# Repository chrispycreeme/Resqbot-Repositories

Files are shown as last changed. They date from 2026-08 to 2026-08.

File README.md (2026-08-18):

# ResQBot: Dual-Node Multi-Sensor Reconnaissance & Search Platform

## Overview

ResQBot is an integrated search and rescue reconnaissance platform designed for real-time human detection, thermal mapping, and remote navigation in hazardous or restricted environments. The system utilizes a dual-microcontroller architecture (ESP32-CAM and ESP32-Main) communicating over a local Wi-Fi network with a central Python desktop station. 

Key capabilities include:
* Real-time visual reconnaissance via ESP32-CAM streaming JPEG frames over HTTP POST.
* Computer vision human detection utilizing YOLO object detection (`person.pt`).
* Infrared thermal telemetry using an MLX90640 array sensor (768-pixel temperature grid) rendered as JET heatmaps.
* Differential propulsion drive utilizing L9110 motor drivers with software-controlled PWM ramping.
* Onboard status monitoring via SSD1306 OLED display and active acoustic buzzer alarms.
* Provisioning interface via captive Wi-Fi Access Point portals on both microcontrollers.
* An interactive web-based technical manual and troubleshooting suite.

---

## Repository Structure

```
resqbot-final/
├── 3D Parts/
│   ├── Compartment.stl          # 3D printable electronics compartment chassis
│   ├── Hinge.stl                # 3D printable door hinge assembly
│   ├── Latch.stl                # 3D printable mechanical enclosure latch
│   ├── Left Hull.stl            # 3D printable left hull section
│   ├── Right Hull.stl           # 3D printable right hull section
│   ├── 1.png                    # Assembly preview / render 1
│   ├── 2.png                    # Assembly preview / render 2
│   ├── 3.png                    # Assembly preview / render 3
│   └── 4.png                    # Assembly preview / render 4
├── esp32cam/
│   └── esp32cam.ino             # ESP32-CAM firmware (OV2640 camera capture, HTTP video uploader)
├── esp32main/
│   └── esp32main.ino            # ESP32-Main station firmware (MLX90640, SSD1306 OLED, L9110, Buzzer)
├── manual_web/
│   ├── index.html               # Web-based operations and technical manual interface
│   ├── styles.css               # Manual stylesheet
│   ├── script.js                # Interactive hotspots, zoom controls, and simulation logic
│   └── perfboard_view.png       # Annotated circuit wiring diagram image
├── python/
│   ├── app.py                   # Central Python desktop app (Flask HTTP server + Tkinter GUI)
│   └── person.pt                # Trained YOLO neural network weights for human detection
├── Project_Price_Quotation_ResqBot_Final.pdf  # Bill of materials and cost breakdown documentation
├── Resqbot Model Specifications.pdf  # Model specifications / CAD documentation
├── ResqBot Schematics.pdf        # Schematic electrical wiring diagrams
└── README.md                    # System documentation
```

---

## Hardware Subsystems

### 1. ESP32-CAM Node
* **Processor:** ESP32 Dual-Core 240 MHz MCU.
* **Sensor:** OV2640 Camera Module (VGA / QVGA resolutions).
* **Role:** Continuous capture of JPEG image frames transmitted via HTTP POST requests to `/upload_cam` on the central server.
* **Provisioning:** Hosts captive access point `ResQBot-CAM-AP` at `192.168.4.1` for configuring Wi-Fi credentials and target host server IP into non-volatile storage (NVS).

### 2. ESP32-Main Control Unit
* **Processor:** ESP32 Dual-Core 240 MHz MCU.
* **Thermal Sensor:** GY-MCU90640 (MLX90640 32x24 IR array) over UART (115200 baud, 1544-byte frame buffer).
* **Display:** 0.96-inch SSD1306 OLED (128x64 pixels, I2C bus at `0x3C`/`0x3D`).
* **Motor Driver:** L9110 Dual Channel H-Bridge Motor Driver supporting PWM speed ramping for Motor A and Motor B.
* **Alarm:** Active 5V Piezo Buzzer triggered on detection alerts or server requests.
* **Provisioning:** Hosts captive access point `ResQBot-Main-AP` at `192.168.4.1` for Wi-Fi and host IP configuration into NVS.

### 3. Power and Electrical Regulation
* **Primary Source:** 3S Li-ion Battery pack.
* **Voltage Regulation:** LM2596 DC-DC Buck Converter calibrated to 5.00V DC.
* **Charging Interface:** Integrated 3S Type-C charging circuit with status LED indication.
* **Switching Isolation:** Dual-position Rocker Switch toggling between System Power ON (Position I) and Charge Mode (Position O) to protect onboard microcontrollers during charging.

### 4. Structural Hull and Mechanical CAD
* STL files for full hull assembly are provided in the `3D Parts/` folder, including Left and Right Hulls, Electronics Compartment, Hinge, and Latch mechanisms.

---

## Technical Specifications

### 1. Computer Vision AI Model Specifications
* **Model Architecture:** YOLO (You Only Look Once) neural network object detector optimized for real-time human detection.
* **Weights File:** `person.pt`
* **Target Class:** Class `0` (Person / Human Detection).
* **Confidence Threshold:** `0.35` (`conf=0.35`).
* **Input Resolution:** Scaled to 480x360 pixels from incoming JPEG video streams (VGA / QVGA).
* **Inference Pipeline:** PyTorch / Ultralytics YOLO inference integrated with OpenCV bounding box annotations and automatic buzzer alert triggers.

### 2. Microcontroller & Processing Specifications
* **ESP32-Main Node:**
  * Processor: Tensilica Xtensa Dual-Core 32-bit LX6 @ 240 MHz.
  * Memory: 520 KB SRAM, 4 MB Flash memory.
  * Wireless Connectivity: Wi-Fi 802.11 b/g/n, Bluetooth v4.2 BR/EDR & BLE.
  * Operating Voltage: 3.3V Logic (5.0V VCC input from buck regulator).
* **ESP32-CAM Node:**
  * Module Type: AI-Thinker ESP32-CAM.
  * Camera Sensor: Omnivision OV2640 2 MP Image Sensor.
  * Video Formats: JPEG streaming over HTTP POST at VGA (640x480) / QVGA (320x240).
  * External Memory: 4 MB PSRAM for multi-buffer frame buffering.

### 3. Sensor Module Specifications
* **Far-Infrared Thermal Sensor (GY-MCU90640 / MLX90640):**
  * Sensor Array Resolution: 32 x 24 IR pixels (768 total temperature data points).
  * Field of View (FOV): 55° x 35° / 110° x 75°.
  * Temperature Measurement Range: -40°C to +300°C.
  * Interface: Hardware UART @ 115200 Baud (1544-byte raw frame packet).
* **Ultrasonic Distance Sensor:**
  * Interface: Serial UART (GPIO 5 TX / GPIO 18 RX).
* **Status OLED Display:**
  * Screen Size: 0.96 inch SSD1306 Monochrome Display.
  * Resolution: 128 x 64 pixels.
  * Bus Protocol: I2C (Default address `0x3C` / `0x3D`, SDA GPIO 21, SCL GPIO 22).
* **Acoustic Alert:**
  * Active 5V Piezoelectric Buzzer on GPIO 27.

### 4. Propulsion & Motor Control Specifications
* **Motor Driver:** L9110S Dual-Channel H-Bridge Motor Driver Module.
* **Continuous Current:** 800 mA per channel (1.5 A peak).
* **Operating Voltage:** 2.5V to 12V DC.
* **Control Method:** 4-Channel PWM speed ramping (5 kHz frequency, 8-bit resolution: 0 - 255).
* **Drive System:** Differential steering (Independent Left/Right propulsion thrusters).

### 5. Power & Voltage Regulation Specifications
* **Battery Pack:** 3S Li-ion Battery Configuration (11.1V nominal, 12.6V max charge).
* **Logic Voltage Regulator:** Mini-360 / LM2596 DC-DC Buck Converter outputting 5.00V DC for MCU and sensor logic.
* **Motor Voltage Regulator:** Dedicated Mini-360 DC-DC Buck Converter supplying high-current power rail for L9110 motor driver.
* **Charging Interface:** Integrated 3S 2A Type-C Lithium Battery Charger Module with series cell balancing (`B+`, `B2`, `B1`, `B-`).

---

## Software Architecture

### Central Desktop Control Station (`python/app.py`)
The primary operator interface combines a multi-threaded Flask HTTP server with a Tkinter dashboard interface:

1. **Flask API Endpoints:**
   * `POST /upload_cam`: Ingests binary JPEG camera frames from the ESP32-CAM.
   * `POST /upload_mlx`: Ingests 768-element floating-point temperature arrays from the ESP32-Main. Returns motor target speeds and active person detection counts.
   * `GET/POST /motor`: Provides query and command interfaces for differential motor channels.
   * `GET/POST /motorStop`: Issues immediate emergency stop commands to both motor channels.

2. **Computer Vision & Thermal Pipeline:**
   * **YOLO Person Detection:** Processes incoming visual frames against `person.pt` model weights, drawing bounding boxes and calculating total detected individuals.
   * **Thermal Heatmap Processing:** Normalizes raw temperature matrices and applies the OpenCV `COLORMAP_JET` transformation, displaying localized minimum, maximum, and average temperatures.

3. **WASD Steering & Speed Ramping Engine:**
   * Maps keyboard inputs (`W`, `A`, `S`, `D`, `Spacebar`) into differential motor targets for Forward, Reverse, Spin Left, Spin Right, and Emergency Stop operations.
   * Implements software ramping algorithms to ensure smooth acceleration and deceleration curves.

---

## Web Operations Manual (`manual_web/`)

The repository includes a web-based technical manual that can be rendered in any modern web browser. Features include:
* **System Architecture Breakdown:** Technical descriptions of hardware and software workflows.
* **Interactive Hardware Viewer:** Circuit diagram navigation with zoom, pan, and interactive hotspots describing pin connections.
* **Commissioning Timeline:** Step-by-step startup, calibration, provisioning, and charging procedures.
* **Filterable Troubleshooting Matrix:** Searchable resolution protocols for power, camera, thermal sensor, motor driver, display, and network issues.
* **Control Simulator:** Integrated keyboard steering and motor PWM output preview tool.

---

## Getting Started

### System Prerequisites
* **Python Environment:** Python 3.10 or higher.
* **Firmware Build Environment:** Arduino IDE with ESP32 board support packages (`esp32` by Espressif Systems).

### Python Dependencies Installation
Install required dependencies prior to launching the control station:
```bash
pip install ultralytics opencv-python pillow flask requests numpy
```

### Firmware Flashing
1. **ESP32-CAM Node:**
   * Open `esp32cam/esp32cam.ino` in Arduino IDE.
   * Select board: **AI Thinker ESP32-CAM**.
   * Enable PSRAM if supported by your module.
   * Flash firmware to the ESP32-CAM board.

2. **ESP32-Main Station:**
   * Open `esp32main/esp32main.ino` in Arduino IDE.
   * Select board: **ESP32 Dev Module**.
   * Required libraries: `Adafruit_GFX`, `Adafruit_SSD1306`, `Preferences`, `Wire`, `WiFi`, `HTTPClient`.
   * Flash firmware to the ESP32-Main board.

### Commissioning and Operation Workflow

1. **Power Supply Calibration:**
   * Set the Rocker Switch to Position O (Charge Mode).
   * Disconnect microcontrollers from the 5V rail.
   * Toggle Rocker Switch to Position I and verify LM2596 output reads exactly 5.00V DC using a multimeter.

2. **Launch Control Station Server:**
   * Navigate to the `python/` directory and run:
     ```bash
     python app.py
     ```
   * Record the host IP address displayed in the window title bar (e.g., `http://192.168.18.155:5000`).

3. **Network Provisioning:**
   * **ESP32-CAM:** Connect PC or mobile device to Wi-Fi AP `ResQBot-CAM-AP`. Open browser at `http://192.168.4.1`, input your Wi-Fi SSID, Password, and Server Host IP, then click **Connect & Continue Operations**.
   * **ESP32-Main:** Connect to Wi-Fi AP `ResQBot-Main-AP`. Open browser at `http://192.168.4.1`, input identical Wi-Fi SSID, Password, and Server Host IP, then click **Connect & Continue Operations**.

4. **Telemetry Verification and Control:**
   * Observe OLED status on the main node: verify Wi-Fi connection, Python app connection status, and MLX sensor readiness.
   * Monitor the desktop station GUI for video feeds, person bounding boxes, and thermal heatmaps.
   * Drive the robot using WASD keys or on-screen slider controls.

---

## Telemetry and API Endpoint Reference

| Endpoint | Method | Payload / Parameters | Description |
| :--- | :--- | :--- | :--- |
| `/upload_cam` | `POST` | Binary JPEG buffer | Receives image frame from ESP32-CAM node |
| `/upload_mlx` | `POST` | JSON array of 768 float values | Receives thermal telemetry array from ESP32-Main node |
| `/motor` | `GET / POST` | `ch` (A/B), `speed` (-255 to 255) | Queries or updates target channel speeds |
| `/motorStop` | `GET / POST` | None | Halts both motor channels immediately |
| `/beep` | `GET / POST` | `ms` (duration in milliseconds) | Triggers active buzzer alert |

---

## Safety Guidelines

* **Charging Isolation:** Always toggle the main Rocker Switch to Position O (Charge Mode) before connecting a Type-C charging cable. Charging while the system is powered on can damage sensitive electronics.
* **Reverse Polarity Warning:** Verify wiring connections against `ResqBot Schematics.pdf` before applying battery power. Reversed polarity will destroy microcontroller components.
* **Thermal Management:** Ensure LM2596 regulator and L9110 motor driver modules have sufficient airflow during high-load motor operations.

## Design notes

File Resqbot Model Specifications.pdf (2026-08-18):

# TECHNICAL SPECIFICATIONS

# ResqBot - Catamaran Based Chassis

# 1. Executive Summary & Design Overview

The structural, dimensional, and material specifications for a lightweight, twin-hull (catamaran). Specifically for additive manufacturing using PETG (Polyethylene Terephthalate Glycol).

The catamaran-style configuration provides enhanced lateral stability in surface water conditions, while space-frame lattice arms distribute dynamic loading from the pontoon hulls into the central payload compartment.

# 2. Bounding Dimensions & Physical Envelope

Dimension Parameter | Value | Description / Reference
Overall Length (OAL) | 409.00 mm | Maximum longitudinal profile along the pontoon axis
Overall Beam (Width) | 412.00 mm | Total horizontal span from port to starboard hull outer edges
Overall Height (OAH) | 180.00 mm | Total vertical height from keel base to tail fin apex
Lattice Arm Diagonal Span | 199.25 mm | Structural truss frame length connecting hulls to central bay
Pontoon Mount Footprint | 110.90 × 52.00 mm | Contact interface block for lattice arm pontoon mounting
Central Bay Footprint | 171.05 × 130.49 mm | Top deck profile envelope for main payload compartment

# 3. Material & Structural Wall Thickness Profile

To optimize displacement and weight distribution while maintaining mechanical strength under wave impact, the chassis utilizes a differential wall thickness strategy:

+-----------------------------------------------------------------------+
| SUB-ASSEMBLY ZONE | | PETG WALL THICKNESS | SLICER / PRINT SPEC | |
+------------------------+---------------------+------------------------+
| Hinge Joints & Fins | | 4.0 mm - 5.0 mm | | 10+ Perimeters / Solid |
| Central Bay & Arms | | 2.5 mm - 3.0 mm | | 6-7 Perimeters | |
| Pontoon Hulls | | 2.0 mm - 2.5 mm | | 5-6 Perimeters | |
+-----------------------------------------------------------------------+

## 3.1 Fabrication & Slicer Specifications

- Primary Filament: PETG (Polyethylene Terephthalate Glycol)
- Pontoon Shells ( | ): Designed to minimize dead weight below
the waterline while providing sufficient impact resistance against debris.
- Central Bay & Lattice Arms ( | ): Higher wall density to
absorb hull torsion during differential wave action and support internal payload mass.
- Hinge Assemblies & Tail Fins ( | ): Near-solid printing
required around pivot pin bores to handle shearing stress and dynamic tail fin drag.

# 4. Subsystem Layout & Internal Architecture

## 4.1 Pontoon Hulls (Port & Starboard)

- Hull Geometry: Hydrodynamic, low-drag displacement profile with a tapered bow.
- Internal Cavity: Hollow pontoon structure yielding an estimated
internal volume of | per hull.
- Reserve Buoyancy Integration: High-density, custom-trimmed EVA foam blocks are inserted directly into the hollow pontoon cavities to guarantee positive flotation in the event of an outer shell breach.
- Retention Method: Secured via friction fitting or marine-grade silicone adhesive (RTV sealant). No internal structural recessed channels are needed.

## 4.2 Structural Lattice Arms

- Truss Architecture: Triangular space-frame geometry designed to distribute hydrodynamic drag evenly across the vessel frame.
- Structural Span: | per side, providing a wide $412\text{
mm}$ total beam for stability against capsizing.

## 4.3 Central Electronics Compartment

- Envelope: | .
- Internal Component Integration: All power distribution, logic boards, battery cells, sensors, and charging modules are fully enclosed within the compartment.
- Ingress Protection Strategy: The exterior of the central housing is printed solid on all sides (no front camera/sensor aperture cutouts) to protect against head-on wave splashes. Charging terminals and debug ports remain internal; access is conducted via the top hatch.

# 5. Port Geometry & Wiring Pass-Throughs

Port Designation | Location | Dimensions | Quantity | Primary Function
Motor Ports | Rear Face | | 2 Wire lead routing | & propulsion motor mounts
Front Optics Port | Front Face | | 2 “Eye” sockets for | the camera (Thermal and Visual)
Front Middle Optic Port | Front Face | | 1 Slot for the | ultrasonic sensor right below the front optics to ensure close relative field of view.

## Sealing Protocol

To maintain watertight integrity, the rear | motor ports must
be sealed after wire harness installation using rubber cable grommets or silicone seal potting compound.

# 6. System Summary Matrix

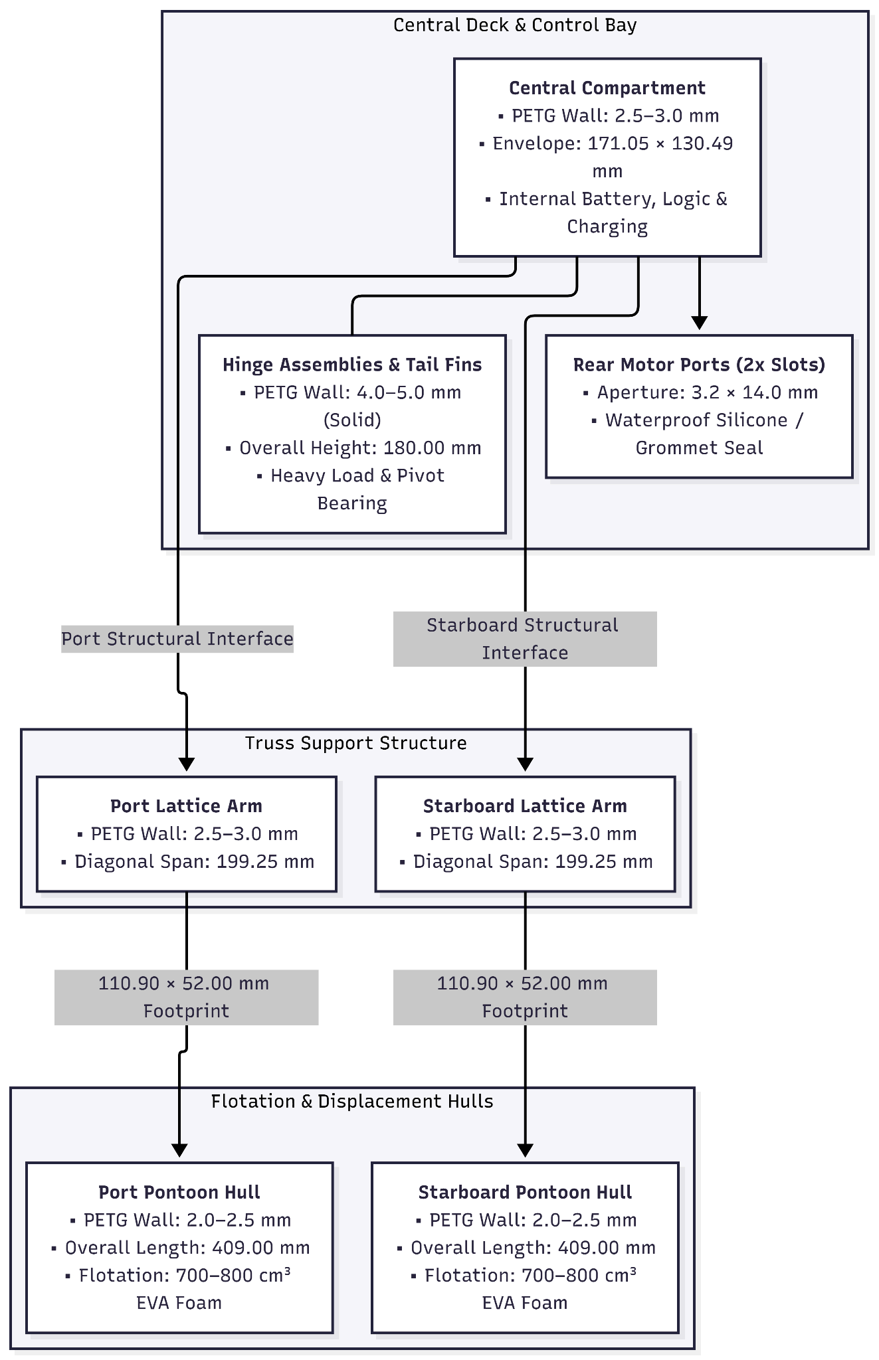
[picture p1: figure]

# 7. Complete Visual Presentation of Each Part

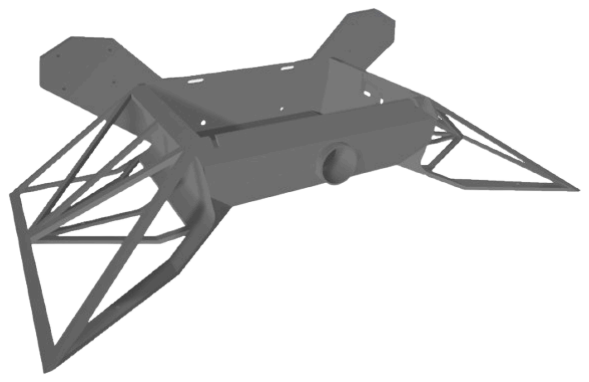
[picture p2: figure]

### A. Compartment

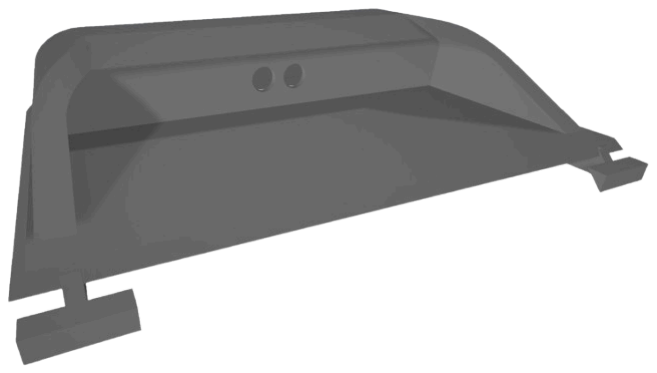
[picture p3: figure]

### B. Top Hatch / Lid

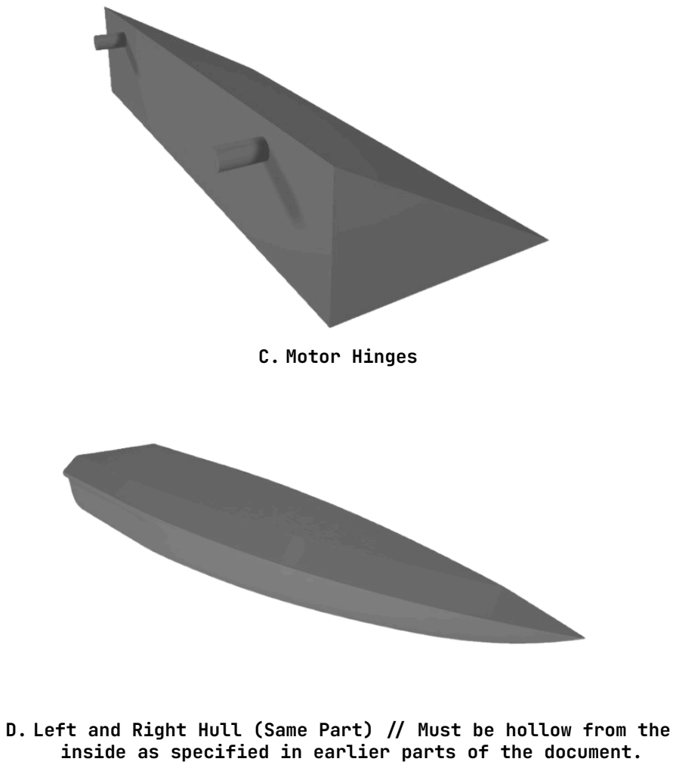
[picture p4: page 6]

### C. Motor Hinges

### D. Left and Right Hull (Same Part) / Must be hollow from the

inside as specified in earlier parts of the document.

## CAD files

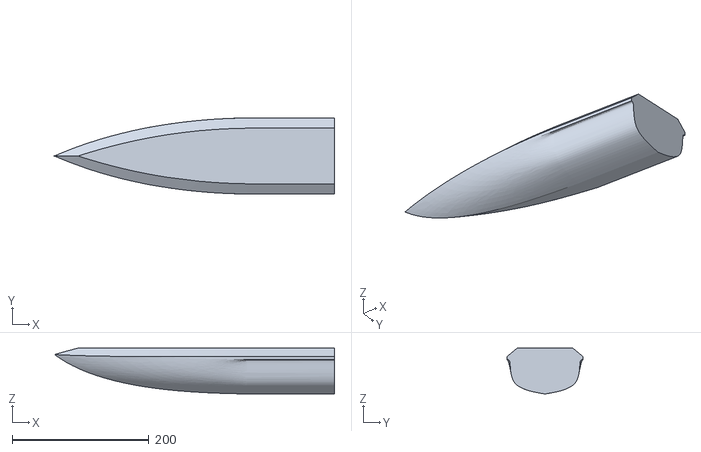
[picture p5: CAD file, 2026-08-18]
3D Parts/Right Hull.stl
409.1 x 111.2 x 67.1

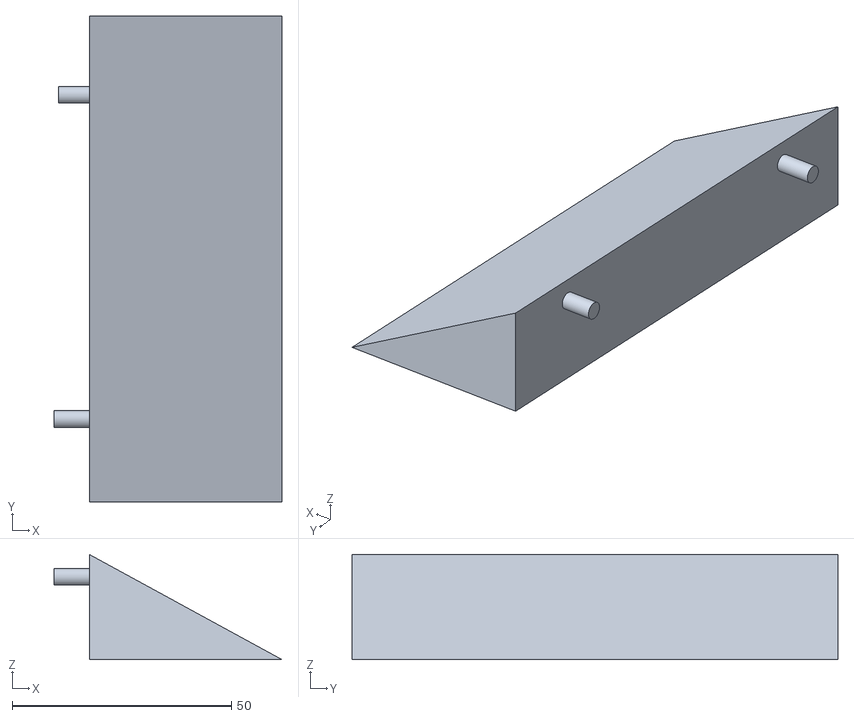
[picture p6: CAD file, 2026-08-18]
3D Parts/Hinge.stl
52.0 x 110.9 x 24.0

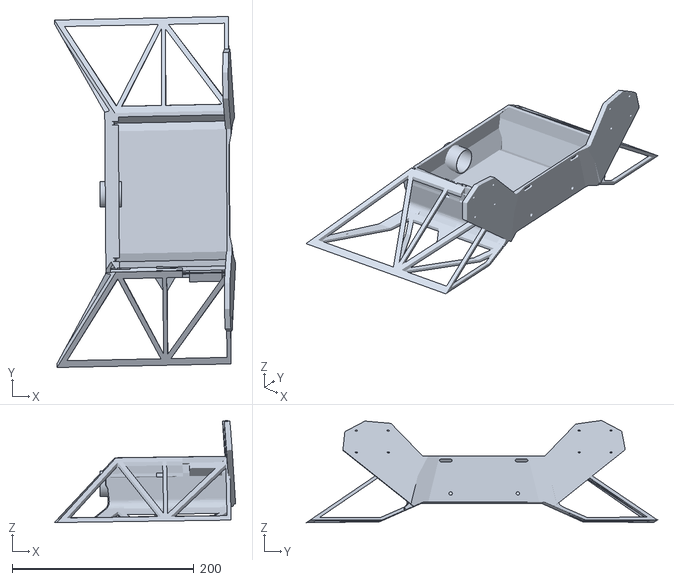
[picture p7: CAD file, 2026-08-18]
3D Parts/Compartment.stl
199.3 x 385.8 x 112.2

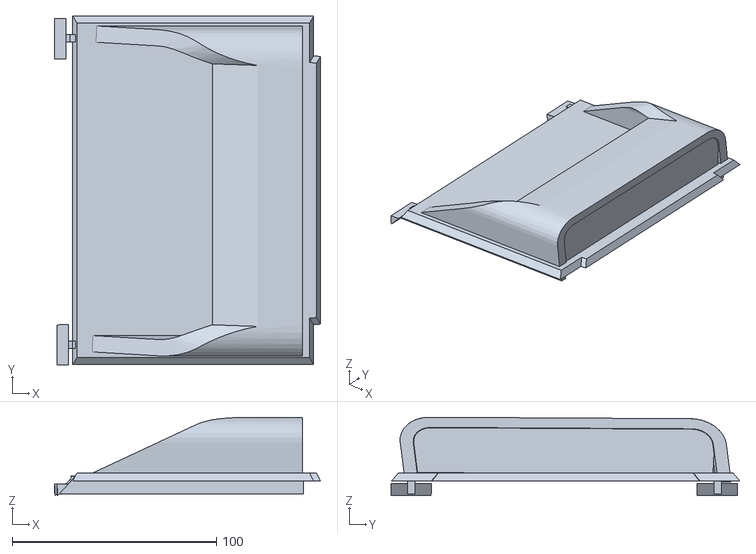
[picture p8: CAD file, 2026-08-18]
3D Parts/Latch.stl
130.5 x 171.0 x 38.5

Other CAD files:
3D Parts/Left Hull.stl

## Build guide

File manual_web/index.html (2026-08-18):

R

# ResQBot Operations & Technical Manual

REV v2.4 PLATFORM: ESP32 / PYTHON

1.0

## System Architecture & Overview

Technical breakdown of the ResQBot dual-microcontroller reconnaissance platform and desktop station integration.

### Dual Microcontroller Architecture

ResQBot utilizes two independent ESP32 microcontrollers to segregate video capture and sensor telemetry workloads:

- ESP32-CAM Node: Dedicated OV2640 camera streaming node posting binary JPEG frames over HTTP POST to the central server.
- ESP32-Main Station Node: Core processing node parsing MLX90640 thermal UART telemetry, driving the SSD1306 OLED, executing L9110 motor PWM ramping, and controlling the alarm buzzer.

### Python Control Station & AI Pipeline

The central Flask and Tkinter application hosted on the PC processes raw stream feeds in real time:

- YOLO Person Detection: Evaluates incoming JPEG frames using the person.pt neural network model.
- Thermal JET Interpolation: Converts 768 floating-point temperature values into a 24x32 color-mapped thermal matrix.
- WASD Steering Engine: Translates operator key controls into differential motor PWM speed targets.

SAFETY PROTOCOL SUMMARY

Always ensure the main Rocker Switch is set to Position O (Charge Mode) before plugging in USB Type-C charging power. Operating or charging with reversed polarity will result in permanent hardware damage.

2.0

## Perfboard Circuit Diagram

Select any numbered component pin on the diagram below to inspect technical specifications, electrical connections, operating protocols, and precautions.

Hardware Component Viewer

Zoom In (+) Zoom Out (-) Reset View Hotspots: ON

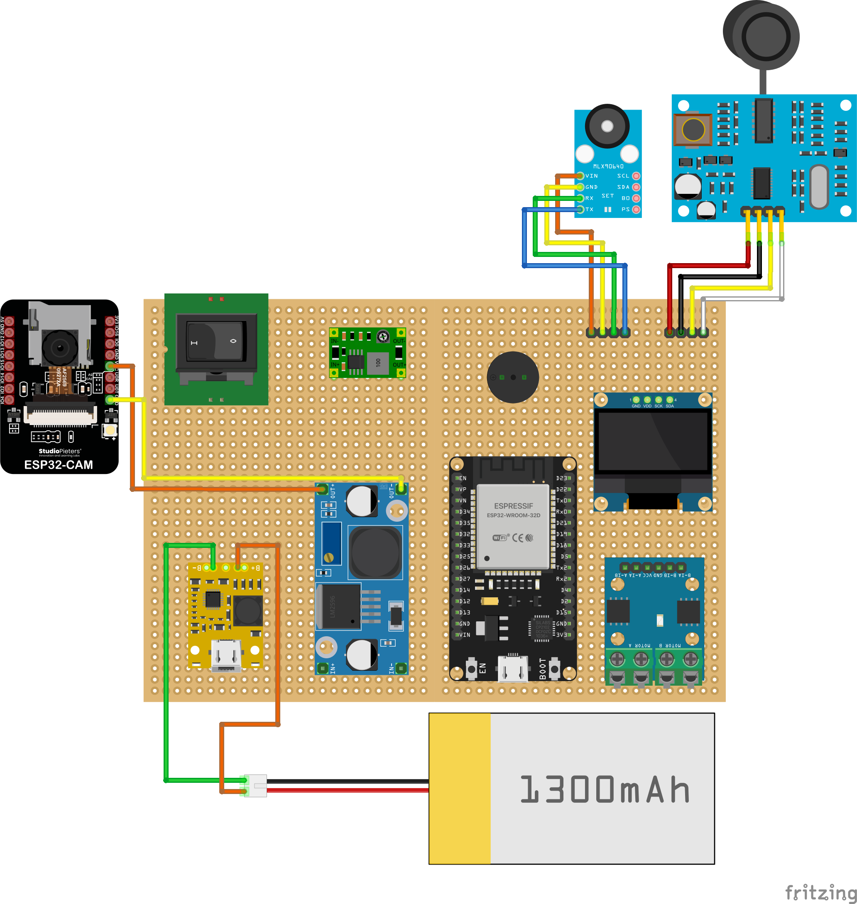
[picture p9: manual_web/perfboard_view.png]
ResQBot Perfboard Circuit Diagram


3.0

## Step-by-Step Commissioning & Boot Guide

Sequential operations workflow to safely verify hardware wiring, initialize host software, provision microcontrollers, and operate the robot.

01

Physical Wiring & Electrical Calibration

Before applying main battery power, verify all electrical connections and rail voltages using a digital multimeter.

- Confirm 3S battery leads are wired to the 3S charger module: BAT+ (Red) and BAT- (Black).
- Verify the LM2596 buck converter input terminals connect to the switched output of the Rocker Switch.
- Voltage Calibration: Disconnect microcontrollers from the 5V rail. Toggle Rocker Switch to Position I and measure LM2596 output with a multimeter. Adjust brass potentiometer until output reads exactly 5.00V DC.
- Ensure a shared common ground bus links all GND pins across ESP32-Main, ESP32-CAM, OLED, MLX sensor, Ultrasonic sensor, Buzzer, and L9110 motor driver.

02

Python Environment Setup & Model Deployment

Install required Python 3.10+ dependencies and verify neural network weight files.

Run package installation in terminal:

pip install ultralytics opencv-python pillow flask requests numpy

Confirm that the YOLO neural network model file person.pt is located inside the python/ folder.

03

Host Server Launch & Local IP Identification

Execute the central desktop control station and record the host IP address.

Start the application server:

python python/app.py

Observe the window header displaying the host address: Server Running @ http://<HOST_IP>:5000 (e.g. http://192.168.18.155:5000). Note this IP address for provisioning steps.

04

System Power On & Microcontroller AP Provisioning

Provision WiFi credentials and server target IP into NVS flash memory on both microcontrollers.

1. Toggle main Rocker Switch to Position I (System Power ON).
2. ESP32-CAM Provisioning: Connect PC/mobile to WiFi AP ResQBot-CAM-AP. Navigate browser to http://192.168.4.1. Input local WiFi SSID, Password, and Server IP. Click Connect & Continue Operations.
3. ESP32-Main Provisioning: Connect PC/mobile to WiFi AP ResQBot-Main-AP. Navigate browser to http://192.168.4.1. Input identical local WiFi SSID, Password, and Server IP. Click Connect & Continue Operations.

05

Telemetry Verification & Steering Operations

Verify active stream feeds and test differential motor steering controls.

- Inspect SSD1306 OLED display on robot: verify WiFi: Connected, Python App: Connected, and MLX: OK.
- Inspect Python Desktop App GUI: verify live camera feed with YOLO bounding boxes and thermal JET heat map display.
- Click inside Tkinter window and test WASD steering: W (Forward), S (Reverse), A (Spin Left), D (Spin Right), Spacebar (Emergency Stop).

06

Shutdown & 3S Type-C Charging Protocol

Safely isolate electronics and execute battery charging procedure.

1. Press Spacebar in app window to stop motor outputs.
2. Toggle Rocker Switch to Position O (Charge Mode) to disconnect system electronics.
3. Plug USB Type-C charging cable into 3S charger module port.
4. Verify Red LED is lit during charging. Disconnect charger once Blue LED indicates full charge.

4.0

## Subsystem Specifications & Access Point Interface

Detailed hardware and software protocols for camera streaming, thermal sensor parsing, and control desktop station.

### ESP32-CAM Node Specifications

OV2640 camera node streaming binary JPEG buffers over HTTP POST.

HTTP Telemetry Endpoint

http://<HOST_IP>:5000/upload_cam

Frame Resolution

VGA (640x480) with PSRAM enabled; QVGA (320x240) fallback.

### ESP32-Main Station Specifications

Master MCU parsing MLX90640 UART telemetry and handling motor PWM ramping.

Thermal Telemetry Endpoint

http://<HOST_IP>:5000/upload_mlx

UART Configuration

115200 Baud | 1544 Byte Frame Buffer

http://192.168.4.1/

## ResQBot Camera Module

WiFi & Host Server Setup

WiFi Network (SSID):

ResQBot_Rescue_Net

WiFi Password:

• • • • • • • •

Host PC / Server IP Address:

192.168.18.155

Connect & Continue Operations

AP IP: 192.168.4.1

Figure 4.1: ESP32-CAM Captive Portal Interface (http://192.168.4.1)

http://192.168.4.1/

## ResQBot Main Station

WiFi & Host Server Setup

WiFi Network (SSID):

ResQBot_Rescue_Net

WiFi Password:

• • • • • • • •

Host PC / Server IP Address:

192.168.18.155

Connect & Continue Operations

AP IP: 192.168.4.1

Figure 5.1: ESP32-Main Station Captive Portal Interface (http://192.168.4.1)

### Keyboard Steering & Motor PWM Simulator

Press keys on keyboard (W, A, S, D) or click buttons below to simulate motor output:

WFWD

ALEFT

SREV

DRIGHT

STEERING: [STOPPED]

PROPELLER MOTOR A 0

PROPELLER MOTOR B 0

5.0

## Diagnostic & Troubleshooting Matrix

Search or filter resolution protocols for power, connectivity, sensor, and motor failure modes.

All Scenarios Power & Charging Camera Thermal Sensor Motors Display & App

Scenario 1: Robot does not turn on or shuts down under motor load Power System

Possible Cause: Switch set to Charge Mode, low battery voltage, or LM2596 loose wire connection.

Action:

1. Verify Rocker Switch is toggled to Position I (System Power ON).
2. Measure battery voltage with multimeter across BAT+ and BAT- (must be >10.5V DC).
3. Inspect LM2596 screw terminals and verify OUT+ output reads 5.00V DC.

Scenario 2: Battery fails to charge when Type-C cable is connected Charging

Possible Cause: Switch left in Position I, faulty USB cable, or battery terminal disconnected.

Action:

1. Switch MUST be set to Position O (Charge Mode) during charging.
2. Verify the Red LED on 3S charger module illuminates. If no LED lights, test with another Type-C cable and 5V/2A power adapter.
3. A Blue LED indicates battery is already fully charged.

Scenario 3: ESP32-CAM video stream offline or missing in Python app Camera

Possible Cause: Server IP address mismatch, Windows Firewall blocking port 5000, or insufficient 5V supply current.

Action:

1. Connect smartphone to ResQBot-CAM-AP, navigate to 192.168.4.1, and verify your Host PC IP address.
2. Allow Python through firewall for Port 5000.
3. Ensure ESP32-CAM receives steady 5V power supply from regulator output rail.

Scenario 4: OLED shows "MLX: NO" or thermal heatmap is frozen Thermal Sensor

Possible Cause: Loose UART wires (RX2/TX2), swapped RX/TX lines, or missing 1.5s boot delay.

Action:

1. Confirm MLX90640 TX is wired to ESP32 GPIO 16 (RX2), and MLX RX to GPIO 17 (TX2).
2. Ensure sensor receives stable power. Wait 5 seconds for auto-healing loop to re-initialize UART connection.

Scenario 5: Motors spin in reverse direction or ignore WASD controls Motor Driver

Possible Cause: Reversed motor terminal leads or lost window focus in Python app window.

Action:

1. If Motor A spins backward when pressing W, swap the two output wires connected to MOTOR A screw terminal on L9110 driver.
2. Click inside Tkinter desktop window to ensure keyboard focus for WASD steering.

Scenario 6: SSD1306 OLED display remains completely dark on boot Display

Possible Cause: Swapped SDA/SCL pins, wrong I2C address, or loose power connection.

Action:

1. Verify OLED SDA connects to GPIO 21 and SCL to GPIO 22.
2. Check that VDD receives 5V (or 3.3V) and GND is securely connected. ESP32-Main code automatically scans I2C addresses 0x3C and 0x3D.

Scenario 7: Alarm buzzer does not sound when person is detected Buzzer

Possible Cause: Loose GPIO 27 connection, passive buzzer used instead of active buzzer, or missing person.pt model file.

Action:

1. Ensure an Active 5V Piezo Buzzer is wired to GPIO 27.
2. Confirm person.pt model file exists in python/ directory.
3. Test buzzer manually by accessing http://<ESP32_IP>/beep in web browser.

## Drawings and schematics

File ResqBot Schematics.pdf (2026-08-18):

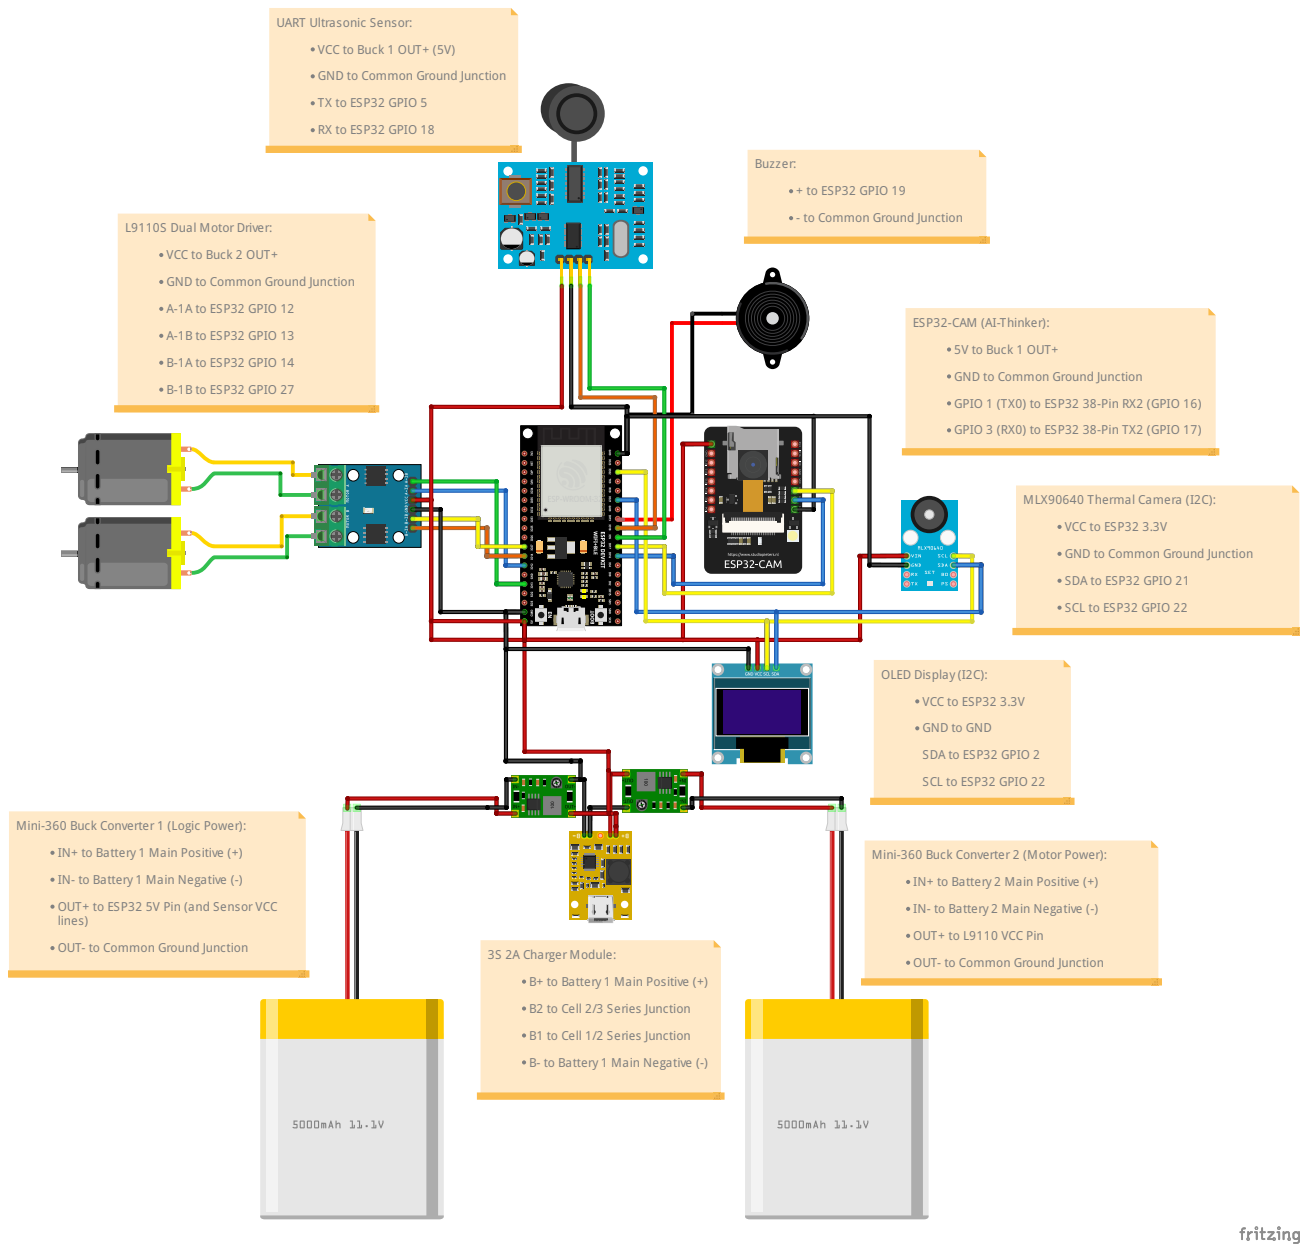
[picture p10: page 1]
Buzzer:; + to ESP32 GPIO 19; MLX90640 Thermal Camera (I2C):; VCC to ESP32 3.3V; OLED Display (I2C):; A-1A to ESP32 GPIO 12; A-1B to ESP32 GPIO 13; B-1A to ESP32 GPIO 14; B-1B to ESP32 GPIO 27; 3S 2A Charger Module:

UART Ultrasonic Sensor:

VCC to Buck 1 OUT+ (5V)

GND to Common Ground Junction

TX to ESP32 GPIO 5

RX to ESP32 GPIO 18

- to Common Ground Junction

L9110S Dual Motor Driver:

VCC to Buck 2 OUT+

ESP32-CAM (AI-Thinker):

5V to Buck 1 OUT+

GPIO 1 (TX0) to ESP32 38-Pin RX2 (GPIO 16)

GPIO 3 (RX0) to ESP32 38-Pin TX2 (GPIO 17)

SDA to ESP32 GPIO 21

SCL to ESP32 GPIO 22

GND to GND

SDA to ESP32 GPIO 2

Mini-360 Buck Converter 1 (Logic Power):

IN+ to Battery 1 Main Positive (+)

Mini-360 Buck Converter 2 (Motor Power):

IN- to Battery 1 Main Negative (-)

IN+ to Battery 2 Main Positive (+)

OUT+ to ESP32 5V Pin (and Sensor VCC
lines)

IN- to Battery 2 Main Negative (-)

OUT+ to L9110 VCC Pin

OUT- to Common Ground Junction

B+ to Battery 1 Main Positive (+)

B2 to Cell 2/3 Series Junction

B1 to Cell 1/2 Series Junction

B- to Battery 1 Main Negative (-)

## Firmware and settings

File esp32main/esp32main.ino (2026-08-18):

#include <Arduino.h>
#include <WiFi.h>
#include <WebServer.h>
#include <HTTPClient.h>
#include <Wire.h>
#include <Adafruit_GFX.h>
#include <Adafruit_SSD1306.h>
#include <Preferences.h>

Preferences preferences;
String savedSsid = "bawal kumonek";
String savedPass = "cdbanluta24";
String savedServerHost = "192.168.18.155";
bool operationsStarted = false;

const char* AP_SSID = "ResQBot-Main-AP";

const int   SERVER_PORT = 5000;

#define SCREEN_WIDTH 128
#define SCREEN_HEIGHT 64
#define OLED_RESET    -1
#define OLED_SDA_PIN  21
#define OLED_SCL_PIN  22

Adafruit_SSD1306 display(SCREEN_WIDTH, SCREEN_HEIGHT, &Wire, OLED_RESET);
bool oledFound = false;
unsigned long lastOledUpdate = 0;

bool pythonConnected = false;
unsigned long lastPythonSuccessTime = 0;
const unsigned long PYTHON_TIMEOUT_MS = 4000;

#define BUZZER_PIN 27

#define RXD2 16
#define TXD2 17
#define FRAME_BYTES 1544
#define MLX_BAUD 115200

uint8_t buffer[FRAME_BYTES];
float frame[768];
bool newFrameAvailable = false;

bool mlxFound = false;
unsigned long lastMlxByteTime = 0;
unsigned long lastMlxInitTime = 0;
unsigned long lastMlxLogTime = 0;
unsigned long totalFramesReceived = 0;
unsigned long totalFramesSent = 0;

#define MOTOR_A_IA 32
#define MOTOR_A_IB 33

#define MOTOR_B_IA 25
#define MOTOR_B_IB 26

#define PWM_FREQ 5000
#define PWM_RES  8

#define CHAN_A_IA 0
#define CHAN_A_IB 1
#define CHAN_B_IA 2
#define CHAN_B_IB 3

int targetMotorA = 0;
int targetMotorB = 0;
float currentMotorA = 0.0;
float currentMotorB = 0.0;
float rampStep = 10.0;
unsigned long lastRampTime = 0;

unsigned long buzzerStopTime = 0;
bool buzzerActive = false;

WebServer server(80);
char jsonBuffer[8192];
unsigned long lastMotorPoll = 0;

void loadSavedCredentials() {
    preferences.begin("wifi-config", true);
    savedSsid = preferences.getString("ssid", "bawal kumonek");
    savedPass = preferences.getString("pass", "cdbanluta24");
    savedServerHost = preferences.getString("server_host", "192.168.18.155");
    preferences.end();
    Serial.println("[NVS] Loaded WiFi SSID: " + savedSsid);
    Serial.println("[NVS] Loaded Server Host: " + savedServerHost);
}

void saveCredentials(const String& ssid, const String& pass, const String& serverHost) {
    preferences.begin("wifi-config", false);
    preferences.putString("ssid", ssid);
    preferences.putString("pass", pass);
    preferences.putString("server_host", serverHost);
    preferences.end();
    savedSsid = ssid;
    savedPass = pass;
    savedServerHost = serverHost;
    Serial.println("[NVS] Saved new WiFi SSID: " + savedSsid);
    Serial.println("[NVS] Saved new Server Host: " + savedServerHost);
}

void initOledDisplay() {
    Wire.begin(OLED_SDA_PIN, OLED_SCL_PIN);
    if (display.begin(SSD1306_SWITCHCAPVCC, 0x3C) || display.begin(SSD1306_SWITCHCAPVCC, 0x3D)) {
        oledFound = true;
        display.clearDisplay();
        display.setTextSize(1);
        display.setTextColor(SSD1306_WHITE);
        display.setCursor(0, 0);
        display.println("=== ResQBot Main ===");
        display.println("OLED Display OK");
        display.println("Connecting WiFi...");
        display.display();
        Serial.println("[OLED] SSD1306 initialized successfully!");
    } else {
        Serial.println("[OLED] Warning: SSD1306 display not found at 0x3C or 0x3D");
    }
}

void updateOledDisplay() {
    if (!oledFound) return;
    if (millis() - lastOledUpdate < 250) return;
    lastOledUpdate = millis();

    if (millis() - lastPythonSuccessTime > PYTHON_TIMEOUT_MS) {
        pythonConnected = false;
    }

    display.clearDisplay();

    display.setTextSize(1);
    display.setTextColor(SSD1306_BLACK, SSD1306_WHITE);
    display.setCursor(0, 0);
    display.print("   ResQBot Station  ");

    display.setTextColor(SSD1306_WHITE);
    display.setCursor(0, 14);
    if (WiFi.status() == WL_CONNECTED) {
        display.print("WiFi: Connected");
    } else {
        display.print("WiFi: Disconnected");
    }

    display.setCursor(0, 26);
    if (WiFi.status() == WL_CONNECTED) {
        display.print("IP: ");
        display.print(WiFi.localIP().toString());
    } else {
        display.print("IP: Searching...");
    }

    display.setCursor(0, 38);
    if (pythonConnected) {
        display.print("Python App: Connected");
    } else {
        display.print("Python App: Offline");
    }

    display.setCursor(0, 50);
    display.printf("MLX:%s | MA:%d MB:%d", mlxFound ? "OK" : "NO", targetMotorA, targetMotorB);

    display.display();
}

void triggerBuzzer(int durationMs = 150) {
    digitalWrite(BUZZER_PIN, HIGH);
    buzzerStopTime = millis() + durationMs;
    buzzerActive = true;
}

void updateBuzzer() {
    if (buzzerActive && millis() >= buzzerStopTime) {
        digitalWrite(BUZZER_PIN, LOW);
        buzzerActive = false;
    }
}

void writePwm(int pin, int chan, int duty) {
#if defined(ESP_ARDUINO_VERSION_MAJOR) && (ESP_ARDUINO_VERSION_MAJOR >= 3)
    ledcWrite(pin, duty);
#else
    ledcWrite(chan, duty);
#endif
}

void motorWrite(int pinFwd, int chanFwd, int pinRev, int chanRev, int speed) {
    speed = constrain(speed, -255, 255);
    if (speed > 0) {
        writePwm(pinFwd, chanFwd, speed);
        writePwm(pinRev, chanRev, 0);
    } else if (speed < 0) {
        writePwm(pinFwd, chanFwd, 0);
        writePwm(pinRev, chanRev, -speed);
    } else {
        writePwm(pinFwd, chanFwd, 0);
        writePwm(pinRev, chanRev, 0);
    }
}

void setMotorA(int speed) {
    targetMotorA = constrain(speed, -255, 255);
}

void setMotorB(int speed) {
    targetMotorB = constrain(speed, -255, 255);
}

void updateMotorRamping() {
    if (millis() - lastRampTime >= 15) {
        lastRampTime = millis();
        bool changed = false;

        if (currentMotorA < targetMotorA) {
            currentMotorA = min((float)targetMotorA, currentMotorA + rampStep);
            changed = true;
        } else if (currentMotorA > targetMotorA) {
            currentMotorA = max((float)targetMotorA, currentMotorA - rampStep);
            changed = true;
        }

        if (currentMotorB < targetMotorB) {
            currentMotorB = min((float)targetMotorB, currentMotorB + rampStep);
            changed = true;
        } else if (currentMotorB > targetMotorB) {
            currentMotorB = max((float)targetMotorB, currentMotorB - rampStep);
            changed = true;
        }

        if (changed) {
            int speedA = (int)round(currentMotorA);
            int speedB = (int)round(currentMotorB);
            motorWrite(MOTOR_A_IA, CHAN_A_IA, MOTOR_A_IB, CHAN_A_IB, speedA);
            motorWrite(MOTOR_B_IA, CHAN_B_IA, MOTOR_B_IB, CHAN_B_IB, speedB);
        }
    }
}

void setupMotors() {
    pinMode(MOTOR_A_IA, OUTPUT);
    digitalWrite(MOTOR_A_IA, LOW);
    pinMode(MOTOR_A_IB, OUTPUT);
    digitalWrite(MOTOR_A_IB, LOW);

    pinMode(MOTOR_B_IA, OUTPUT);
    digitalWrite(MOTOR_B_IA, LOW);
    pinMode(MOTOR_B_IB, OUTPUT);
    digitalWrite(MOTOR_B_IB, LOW);

#if defined(ESP_ARDUINO_VERSION_MAJOR) && (ESP_ARDUINO_VERSION_MAJOR >= 3)
    ledcAttach(MOTOR_A_IA, PWM_FREQ, PWM_RES);
    ledcAttach(MOTOR_A_IB, PWM_FREQ, PWM_RES);
    ledcAttach(MOTOR_B_IA, PWM_FREQ, PWM_RES);
    ledcAttach(MOTOR_B_IB, PWM_FREQ, PWM_RES);
#else
    ledcSetup(CHAN_A_IA, PWM_FREQ, PWM_RES);
    ledcSetup(CHAN_A_IB, PWM_FREQ, PWM_RES);
    ledcSetup(CHAN_B_IA, PWM_FREQ, PWM_RES);
    ledcSetup(CHAN_B_IB, PWM_FREQ, PWM_RES);

    ledcAttachPin(MOTOR_A_IA, CHAN_A_IA);
    ledcAttachPin(MOTOR_A_IB, CHAN_A_IB);
    ledcAttachPin(MOTOR_B_IA, CHAN_B_IA);
    ledcAttachPin(MOTOR_B_IB, CHAN_B_IB);
#endif

    writePwm(MOTOR_A_IA, CHAN_A_IA, 0);
    writePwm(MOTOR_A_IB, CHAN_A_IB, 0);
    writePwm(MOTOR_B_IA, CHAN_B_IA, 0);
    writePwm(MOTOR_B_IB, CHAN_B_IB, 0);

    targetMotorA = 0;
    targetMotorB = 0;
    currentMotorA = 0.0;
    currentMotorB = 0.0;
}

void initMlxSensor() {
    Serial.printf("[MLX] Initializing GPIO %d (RX) / GPIO %d (TX) @ %d baud...\n", RXD2, TXD2, MLX_BAUD);

    Serial2.end();
    delay(100);

    pinMode(RXD2, INPUT_PULLUP);
    pinMode(TXD2, OUTPUT);

    Serial2.setRxBufferSize(2048);
    Serial2.begin(MLX_BAUD, SERIAL_8N1, RXD2, TXD2);
    delay(200);

    uint8_t cmd1[] = {0xA5, 0x15, 0x01, 0xBB};
    Serial2.write(cmd1, sizeof(cmd1));
    Serial2.flush();
    delay(100);

    uint8_t cmd2[] = {0xA5, 0x35, 0x02, 0xDC};
    Serial2.write(cmd2, sizeof(cmd2));
    Serial2.flush();

    lastMlxInitTime = millis();
}

void parseFrame() {
    float minT = 999.0f, maxT = -999.0f, sumT = 0.0f;
    for (int i = 0; i < 768; i++) {
        uint8_t hi = buffer[4 + i * 2];
        uint8_t lo = buffer[5 + i * 2];
        int16_t rawTemp = (int16_t)((hi << 8) | lo);
        float t = rawTemp / 100.0f;
        frame[i] = t;
        if (t < minT) minT = t;
        if (t > maxT) maxT = t;
        sumT += t;
    }
    newFrameAvailable = true;
    totalFramesReceived++;

    if (totalFramesReceived == 1 || millis() - lastMlxLogTime > 3000) {
        lastMlxLogTime = millis();
        Serial.printf("[MLX] Frame #%lu parsed (768 pixels | Min: %.1f C, Max: %.1f C, Avg: %.1f C)\n",
                      totalFramesReceived, minT, maxT, sumT / 768.0f);
    }
}

enum FrameState { SEARCH_5A_1, SEARCH_5A_2, COLLECT };
FrameState state = SEARCH_5A_1;
int idx = 0;

void pollSensor() {
    while (Serial2.available()) {
        uint8_t b = Serial2.read();
        lastMlxByteTime = millis();

        switch (state) {
            case SEARCH_5A_1:
                if (b == 0x5A) {
                    buffer[0] = b;
                    state = SEARCH_5A_2;
                }
                break;

            case SEARCH_5A_2:
                if (b == 0x5A) {
                    buffer[1] = b;
                    idx = 2;
                    state = COLLECT;
                    if (!mlxFound) {
                        mlxFound = true;
                        Serial.printf("\n[MLX] *** MLX90640 SENSOR FOUND & LOCKED! ***\n");
                        Serial.printf("[MLX] Detected on GPIO %d (RX) / GPIO %d (TX) @ %d baud\n\n",
                                      RXD2, TXD2, MLX_BAUD);
                    }
                } else {
                    state = SEARCH_5A_1;
                }
                break;

            case COLLECT:
                buffer[idx++] = b;
                if (idx >= FRAME_BYTES) {
                    parseFrame();
                    state = SEARCH_5A_1;
                    idx = 0;
                }
                break;
        }
    }
}

void checkMlxHealth() {
    unsigned long now = millis();
    if (!mlxFound && (now - lastMlxInitTime > 3000) && (now - lastMlxByteTime > 3000)) {
        Serial.printf("\n[MLX] No response. Re-initializing GPIO %d / %d @ %d baud...\n", RXD2, TXD2, MLX_BAUD);
        initMlxSensor();
    } else if (mlxFound && (now - lastMlxByteTime > 4000)) {
        Serial.println("[MLX] WARNING: MLX90640 stream interrupted (>4s no data). Re-initializing...");
        mlxFound = false;
        initMlxSensor();
    }
}

void buildJson() {
    int pos = 0;
    jsonBuffer[pos++] = '[';
    for (int i = 0; i < 768; i++) {
        pos += snprintf(jsonBuffer + pos, sizeof(jsonBuffer) - pos,
                         "%.1f%s", frame[i], (i < 767) ? "," : "");
    }
    jsonBuffer[pos++] = ']';
    jsonBuffer[pos] = '\0';
}

void parseServerResponse(String payload) {
    int idxA = payload.indexOf("motorA");
    if (idxA != -1) {
        int colonA = payload.indexOf(':', idxA);
        if (colonA != -1) {
            int valA = payload.substring(colonA + 1).toInt();
            setMotorA(valA);
        }
    }
    int idxB = payload.indexOf("motorB");
    if (idxB != -1) {
        int colonB = payload.indexOf(':', idxB);
        if (colonB != -1) {
            int valB = payload.substring(colonB + 1).toInt();
            setMotorB(valB);
        }
    }
    int idxP = payload.indexOf("persons");
    if (idxP != -1) {
        int colonP = payload.indexOf(':', idxP);
        if (colonP != -1) {
            int numPersons = payload.substring(colonP + 1).toInt();
            if (numPersons > 0) {
                triggerBuzzer(150);
            }
        }
    }
}

void sendThermalData() {
    if (!newFrameAvailable) return;
    if (WiFi.status() != WL_CONNECTED) {
        static unsigned long lastWifiWarn = 0;
        if (millis() - lastWifiWarn > 5000) {
            lastWifiWarn = millis();
            Serial.println("[MLX] Cannot send thermal data: WiFi NOT connected!");
        }
        return;
    }

    buildJson();
    newFrameAvailable = false;

    HTTPClient http;
    String url = "http://" + savedServerHost + ":" + String(SERVER_PORT) + "/upload_mlx";

    http.begin(url);
    http.addHeader("Content-Type", "application/json");
    http.setTimeout(1500);

    int httpResponseCode = http.POST((uint8_t*)jsonBuffer, strlen(jsonBuffer));

    if (httpResponseCode == 200) {
        lastPythonSuccessTime = millis();
        pythonConnected = true;
        totalFramesSent++;
        if (totalFramesSent == 1 || totalFramesSent % 20 == 0) {
            Serial.printf("[MLX] Posted frame #%lu to %s -> HTTP 200 OK\n", totalFramesSent, url.c_str());
        }
        String response = http.getString();
        parseServerResponse(response);
    } else {
        Serial.printf("[MLX] Error posting MLX data to %s: HTTP code %d\n", url.c_str(), httpResponseCode);
    }

    http.end();
}

void pollServerForMotors() {
    if (millis() - lastMotorPoll > 200) {
        lastMotorPoll = millis();
        if (WiFi.status() == WL_CONNECTED) {
            HTTPClient http;
            String url = "http://" + savedServerHost + ":" + String(SERVER_PORT) + "/motor";
            http.begin(url);
            http.setTimeout(500);
            int code = http.GET();
            if (code == 200) {
                lastPythonSuccessTime = millis();
                pythonConnected = true;
                parseServerResponse(http.getString());
            }
            http.end();
        }
    }
}

void handleRoot() {
    String html = "<!DOCTYPE html><html><head>"
                  "<meta name='viewport' content='width=device-width, initial-scale=1'>"
                  "<title>ResQBot Main Setup</title>"
                  "<style>"
                  "body{background:#1e1e1e;color:#eee;font-family:sans-serif;text-align:center;padding:20px;margin:0;}"
                  ".card{background:#2d2d2d;max-width:400px;margin:20px auto;padding:25px;border-radius:12px;box-shadow:0 4px 12px rgba(0,0,0,0.5);}"
                  "h2{color:#64B5F6;margin-top:0;}"
                  "label{display:block;text-align:left;margin-top:12px;font-weight:bold;color:#ccc;}"
                  "input[type=text],input[type=password]{width:100%;box-sizing:border-box;padding:12px;margin-top:6px;border:1px solid #444;border-radius:6px;background:#111;color:#fff;font-size:16px;}"
                  "input[type=submit]{background:#4CAF50;color:#fff;border:none;padding:14px;font-size:16px;font-weight:bold;border-radius:6px;cursor:pointer;width:100%;margin-top:20px;}"
                  "input[type=submit]:hover{background:#45a049;}"
                  ".status{margin-top:15px;font-size:14px;color:#888;}"
                  "</style></head><body>"
                  "<div class='card'>"
                  "<h2>ResQBot Main Station</h2>"
                  "<p style='color:#aaa;'>WiFi & Host Server Setup</p>"
                  "<form action='/save' method='POST'>"
                  "<label>WiFi Network (SSID):</label>"
                  "<input type='text' name='ssid' value='" + savedSsid + "' required>"
                  "<label>WiFi Password:</label>"
                  "<input type='password' name='pass' value='" + savedPass + "'>"
                  "<label>Host PC / Server IP Address:</label>"
                  "<input type='text' name='server_host' value='" + savedServerHost + "' required>"
                  "<input type='submit' value='Connect & Continue Operations'>"
                  "</form>"
                  "<div class='status'>AP IP: " + WiFi.softAPIP().toString() + "</div>"
                  "</div></body></html>";
    server.send(200, "text/html", html);
}

void handleSave() {
    if (server.hasArg("ssid")) {
        String ssid = server.arg("ssid");
        String pass = server.hasArg("pass") ? server.arg("pass") : "";
        String serverHost = server.hasArg("server_host") ? server.arg("server_host") : savedServerHost;
        saveCredentials(ssid, pass, serverHost);
    }

    operationsStarted = true;

    WiFi.begin(savedSsid.c_str(), savedPass.c_str());
    Serial.println("[WiFi] Connecting to " + savedSsid);

    String html = "<!DOCTYPE html><html><head>"
                  "<meta name='viewport' content='width=device-width, initial-scale=1'>"
                  "<title>ResQBot Main - Connecting</title>"
                  "<style>"
                  "body{background:#1e1e1e;color:#eee;font-family:sans-serif;text-align:center;padding:30px;margin:0;}"
                  ".card{background:#2d2d2d;max-width:400px;margin:20px auto;padding:25px;border-radius:12px;}"
                  "h2{color:#4CAF50;}"
                  "</style></head><body>"
                  "<div class='card'>"
                  "<h2>Operations Started!</h2>"
                  "<p>Connecting to <b>" + savedSsid + "</b>...</p>"
                  "<p>Server Host: <b>" + savedServerHost + ":5000</b></p>"
                  "<p style='color:#aaa;'>You may close this tab now. The station is now running operations.</p>"
                  "</div></body></html>";
    server.send(200, "text/html", html);
}

void handleData() {
    buildJson();
    server.send(200, "application/json", jsonBuffer);
}

void handleMotor() {
    if (!server.hasArg("ch") || !server.hasArg("speed")) {
        server.send(400, "text/plain", "missing ch or speed");
        return;
    }
    String ch = server.arg("ch");
    int speed = server.arg("speed").toInt();

    if (ch == "A") setMotorA(speed);
    else if (ch == "B") setMotorB(speed);
    else {
        server.send(400, "text/plain", "ch must be A or B");
        return;
    }

    char resp[64];
    snprintf(resp, sizeof(resp), "{\"ch\":\"%s\",\"speed\":%d}", ch.c_str(), speed);
    server.send(200, "application/json", resp);
}

void handleMotorStopAll() {
    setMotorA(0);
    setMotorB(0);
    currentMotorA = 0.0;
    currentMotorB = 0.0;
    server.send(200, "application/json", "{\"status\":\"stopped\"}");
}

void handleBeep() {
    int ms = 150;
    if (server.hasArg("ms")) {
        ms = server.arg("ms").toInt();
    }
    triggerBuzzer(ms);
    server.send(200, "application/json", "{\"status\":\"beeped\"}");
}

void updateOledApMode() {
    if (!oledFound) return;
    if (millis() - lastOledUpdate < 250) return;
    lastOledUpdate = millis();

    display.clearDisplay();
    display.setTextSize(1);
    display.setTextColor(SSD1306_BLACK, SSD1306_WHITE);
    display.setCursor(0, 0);
    display.print("   ResQBot AP Mode  ");

    display.setTextColor(SSD1306_WHITE);
    display.setCursor(0, 14);
    display.print("AP: ");
    display.print(AP_SSID);

    display.setCursor(0, 26);
    display.print("IP: ");
    display.print(WiFi.softAPIP().toString());

    display.setCursor(0, 38);
    display.print("Connect to AP and");

    display.setCursor(0, 50);
    display.print("click Continue!");

    display.display();
}

void setup() {
    digitalWrite(BUZZER_PIN, LOW);
    pinMode(BUZZER_PIN, OUTPUT);
    digitalWrite(BUZZER_PIN, LOW);
    setupMotors();

    Serial.begin(115200);
    delay(500);
    Serial.println("\n=== ESP32 Main (MLX90640 + L9110 + Active Buzzer) Starting ===");

    loadSavedCredentials();

    initOledDisplay();

    Serial.println("[MLX] Waiting 1.5s for GY-MCU90640 Boot...");
    delay(1500);

    initMlxSensor();

    WiFi.setSleep(false);
    WiFi.mode(WIFI_AP_STA);
    WiFi.softAP(AP_SSID);
    Serial.println("[AP] SoftAP Started: " + String(AP_SSID));
    Serial.println("[AP] Visit http://" + WiFi.softAPIP().toString() + " to configure and start operations");

    server.on("/", handleRoot);
    server.on("/save", HTTP_POST, handleSave);
    server.on("/data", handleData);
    server.on("/motor", handleMotor);
    server.on("/motorStop", handleMotorStopAll);
    server.on("/beep", handleBeep);
    server.begin();

    updateOledApMode();
}

void loop() {
    server.handleClient();
    updateMotorRamping();
    updateBuzzer();

    if (!operationsStarted) {
        updateOledApMode();
        delay(10);
        return;
    }

    pollSensor();
    checkMlxHealth();
    sendThermalData();
    if (!newFrameAvailable) {
        pollServerForMotors();
    }
    updateOledDisplay();
}

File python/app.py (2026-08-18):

import os
import sys
import time
import socket
import threading
import requests
import numpy as np
import cv2
import PIL.Image
import PIL.ImageTk
import tkinter as tk
from tkinter import ttk
from flask import Flask, request, jsonify
from ultralytics import YOLO

import logging
log = logging.getLogger('werkzeug')
log.setLevel(logging.ERROR)

state_lock = threading.Lock()

latest_cam_frame = None
latest_cam_timestamp = 0
cam_fps = 0.0
cam_frame_count = 0
cam_fps_timer = time.time()

latest_mlx_data = None
latest_mlx_timestamp = 0
mlx_fps = 0.0
mlx_frame_count = 0
mlx_fps_timer = time.time()

esp32main_ip = None
motor_A_speed = 0
motor_B_speed = 0

person_count = 0

last_sent_A = None
last_sent_B = None

def send_direct_motor_cmd(ch, speed):
    global esp32main_ip, last_sent_A, last_sent_B

    ch_upper = str(ch).upper()
    if ch_upper == 'A':
        if last_sent_A == speed:
            return
        last_sent_A = speed
    elif ch_upper == 'B':
        if last_sent_B == speed:
            return
        last_sent_B = speed

    ip = esp32main_ip
    if ip:
        def _send():
            try:
                requests.get(f"http://{ip}/motor?ch={ch}&speed={speed}", timeout=0.8)
            except Exception:
                pass
        threading.Thread(target=_send, daemon=True).start()

def get_local_ip():
    try:
        s = socket.socket(socket.AF_INET, socket.SOCK_DGRAM)
        s.connect(("8.8.8.8", 80))
        ip = s.getsockname()[0]
        s.close()
        return ip
    except Exception:
        return "127.0.0.1"

flask_app = Flask(__name__)

@flask_app.route('/upload_cam', methods=['POST'])
def upload_cam():
    global latest_cam_frame, latest_cam_timestamp, cam_frame_count, cam_fps, cam_fps_timer
    try:
        data = request.data
        if not data:
            return jsonify({"error": "Empty body"}), 400
        
        np_arr = np.frombuffer(data, np.uint8)
        frame = cv2.imdecode(np_arr, cv2.IMREAD_COLOR)

        if frame is not None:
            with state_lock:
                latest_cam_frame = frame
                latest_cam_timestamp = time.time()
                cam_frame_count += 1
                now = time.time()
                if now - cam_fps_timer >= 1.0:
                    cam_fps = cam_frame_count / (now - cam_fps_timer)
                    cam_frame_count = 0
                    cam_fps_timer = now
            return jsonify({"status": "ok"}), 200
        else:
            return jsonify({"error": "Failed to decode JPEG"}), 400
    except Exception as e:
        return jsonify({"error": str(e)}), 500


@flask_app.route('/upload_mlx', methods=['POST'])
def upload_mlx():
    global latest_mlx_data, latest_mlx_timestamp, mlx_frame_count, mlx_fps, mlx_fps_timer
    global motor_A_speed, motor_B_speed, esp32main_ip
    try:
        esp32main_ip = request.remote_addr
        json_data = request.get_json(force=True, silent=True)
        if json_data is None:
            return jsonify({"error": "Invalid JSON"}), 400

        if isinstance(json_data, list) and len(json_data) == 768:
            arr = np.array(json_data, dtype=np.float32).reshape((24, 32))
            with state_lock:
                latest_mlx_data = arr
                latest_mlx_timestamp = time.time()
                mlx_frame_count += 1
                now = time.time()
                if now - mlx_fps_timer >= 1.0:
                    mlx_fps = mlx_frame_count / (now - mlx_fps_timer)
                    mlx_frame_count = 0
                    mlx_fps_timer = now
                
                resp = {
                    "status": "ok",
                    "motorA": motor_A_speed,
                    "motorB": motor_B_speed,
                    "persons": person_count
                }
            return jsonify(resp), 200
        else:
            return jsonify({"error": "Expected array of 768 numbers"}), 400
    except Exception as e:
        return jsonify({"error": str(e)}), 500


@flask_app.route('/motor', methods=['GET', 'POST'])
def handle_motor_api():
    global motor_A_speed, motor_B_speed
    ch = request.args.get('ch') or request.form.get('ch')
    speed = request.args.get('speed') or request.form.get('speed')
    
    if ch and speed is not None:
        try:
            sp = int(speed)
            sp = max(-255, min(255, sp))
            with state_lock:
                if ch.upper() == 'A':
                    motor_A_speed = sp
                elif ch.upper() == 'B':
                    motor_B_speed = sp
            return jsonify({"status": "ok", "ch": ch, "speed": sp, "persons": person_count})
        except ValueError:
            return jsonify({"error": "Speed must be integer"}), 400

    return jsonify({"motorA": motor_A_speed, "motorB": motor_B_speed, "persons": person_count})


@flask_app.route('/motorStop', methods=['GET', 'POST'])
def handle_motor_stop_api():
    global motor_A_speed, motor_B_speed
    with state_lock:
        motor_A_speed = 0
        motor_B_speed = 0
    return jsonify({"status": "stopped", "motorA": 0, "motorB": 0, "persons": person_count})


def run_flask():
    flask_app.run(host='0.0.0.0', port=5000, debug=False, use_reloader=False)
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
